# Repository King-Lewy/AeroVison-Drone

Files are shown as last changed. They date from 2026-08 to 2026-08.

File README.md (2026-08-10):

# AeroVison-Drone
A drone with a camera that connects to drone goggles to fly in first person view. 3d printed and custom frame. All parts were researched and chosen to not be too expensive, but still high quality. Sub $1000.

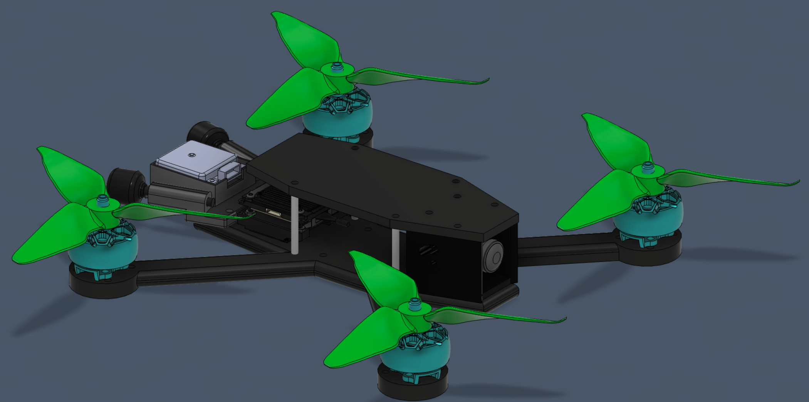
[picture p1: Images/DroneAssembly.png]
Assembly


Assembly with battery on top. 
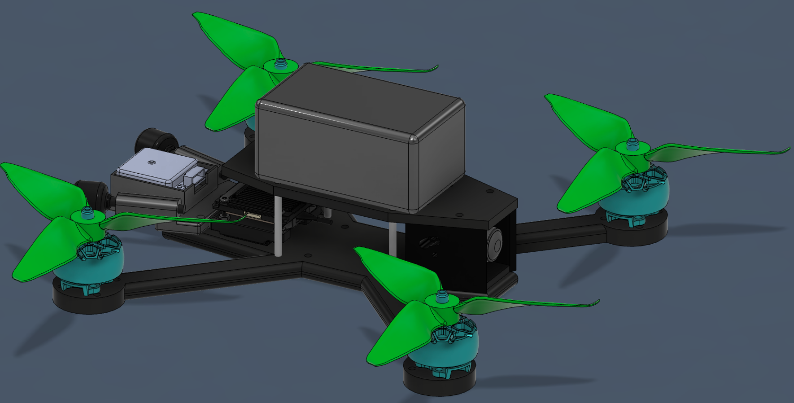
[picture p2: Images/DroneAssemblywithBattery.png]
Assembly with battery


### Why a Drone?
Every since my brother and I got a 3d printed a few years ago, we have wanted to design a drone, and 3d print the frame of it. But, we have never actually got around to doing it, either because we were busy, lazy, or didn't think that we could fund it. But, it was always still in our minds (at least my mind). Making a drone sounded really cool and fun, even though me personally, I didn't know anything about them, how they worked, or how expensive they would be, other than that I assumed that it would cost A LOT to make, which kind of discouraged me. 

## Starting the Project
Just like I mentioned before, I always wanted to make/have a drone, so the idea of making one was very exciting. The reason that I actually started though, was because my dad said that if I design a custom frame, and did all of the work doing all of the parts of designing the drone, he would fund the project for me. I instantly started to research every part of the drone. But, the first thing I did was start with a brainstorming session to get a few guidelines, and base things that needed to be achieved. These were the original guidelines:
 - Low-ish Cost but High Quality (sub $1000)
 - 3d Printed Frame
 - Live Feed Camera with Drone Goggles
 - 100ft Minimum flight height
 - Being Able to have the drone do a flip
 - Be able to survive crashes (I am a beginner, and I know I will crash a few times)

Most of these are basic things that all drones can do, but the one thing (other than a 3d printed frame) that isn't always found is the drone goggles with a live feed camera. This was one baseline that my dad really wanted out of this drone. Because he is funding the project, I can't argue (and I really wanted that too, so I wouldn't argue anyways). I knew that this would dramatically increase the price of this projects, but that's ok.

### Process of Designing a Drone
During research, I learned this process that is used when first starting to design a drone,
1. Choose Frame size
2. Choose Propeller Size (which kind of is chosen with the frame size)
3. Choose Motor Size
4. Choose Battery Voltage

The first thing that I did was find out what size I wanted the drone to be. I researched how big drones are that can fly outside, fast, and won't get blown away hard in the wind. I decided to choose a 5 inch drone (which means the propellers are 5 inch, not the actual frame). This completed the first two steps in the process, which means I needed to find a motor size, and then the battery voltage. 

When choosing the motor size, you have to account for the size of your frame and propellers, because the strength of the motor is in a direct relationship with those. The bigger your frame, the more weight you have to propel, and you need to make sure that the motors fit your propellers, and are strong enough to be used for a 5 inch frame. An additional requirement that I had was to make all of things crash resistant, so I needed a good motor that wouldn't break. I found one that could withstand high voltage, had a steel shaft so it wouldn't break in a crash, and is relatively cheap. 

Based on the size and voltage needed for my motors, that is how I chose my battery. I decided that I needed a 6s battery so there would be enough power to have good flight times, and propel the drone powerfully. Alos, the battery I chose weighed a little more, but that is because I needed it to be able to withstand crashes (per my requirements). 

### Parts Analysis
All of the "big" parts that I have chosen for this drone, I have done an analysis to find the best one that fits this project the best based on it's cost, performance, advantages, disadvantages etc. You can find these analyses in the "Part Analysis-Comparison" folder. These are the main parts the I did an analysis on:
 - Camera and VTX
 - Controllers and Receivers
 - 6s Batteries
 - Filament (When to use which filament)
 - FC+ESC Stack

These are some of the big components for the drone that I decided needed to be really well thought out. The only other big thing that I didn't do an analysis for, was the goggles, because they were the only relatively low cost goggles that still had good camera options.

# Build Instructions
- **Order All of the Necessary Parts**
Go through the BOM and buy all of the parts on the list. Tip: try to get the controller as soon as possible, so you can start practicing on an online simulator. For the 3d printed parts, I would first 3d print all of the parts in a prototype material (pla/petg) and make sure that all of the electronics fit. This also helps you know if there are any problems before printing with a more expensive filament, and it gives you build experience!

- **Assemble the Frame (prototype)**
For the frame, there are a few thing that you will need. The base plate, the standoffs, the top plate, and the mounting pieces for the camera and antenna (with the remote ID). You will assemble the frame first with the prototype material 3d print, to make sure that everything works well. You can also mount all of the electronics if you want, also to make sure the spacing is correct. It all should be fine, but case by case it might be different, and you don't want any problems to occur.

- **Wiring**
This is the hardest part of the whole project. You will need to follow the wiring diagram below to make sure that everything is wired correctly.

To explain the wiring diagram (speedybee V5), the four motors are soldered onto the esc (the bottom of the stack) as well as the cord that connects to the battery, and the capacitor (little cylinder like thing). The order of the motor wires doesn't matter, but for the red and black big wire, the red goes to the positive side, and the black on the negative. The capacitor is the same way. Then, the esc, and fc are connected with a wire provided in the stack kit, and the fc will be on the top. There are three main things that connect to the FC, the receiver, the VTX, and the remote ID/GPS module. The receiver is connected on the specific soldering pods as shown below, but in the patter of (-,gnd)(5V,4V5)(TX,R2)(RX,T2). The VTX is the other part that connects to the receiver, but there is no welding required for this one. On the side of the stack (the one shown in the diagram), there is a wire plug port for a 6 pin wire, which you plug in, then you plug in the other end into the VTX. For this specific design, you have to use a 4 pin to 6 pin wire, because the VTX only has a 4 pin option, and the stack only has a 6 pin, but thankfully, there are wires (in the BOM to account for this). The last thing that connects to the fc (other than the esc) is the remote ID/gps module. This is attached in a very specific manner. Both the remote id, and the stack have 6 pin ports for it to plug into, but there is a big problem, the pin sizes are different, so it won't be able to fit into the stack (because it is smaller). So, you receive a wire in the remote id kit that you will cut of the pin on one side, and keep the other side. You will plug the pin into the slot on the remote id, but for the stack you have to solder it onto the specific ports as shown on the wiring diagram. The only other way to do this (without soldering), is to change the pin size with parts you have, but that is much harder (in my opinion), and I will personally not be doing that. Then, the camera and antennas connect to the vtx in their specific ports as shown in the image.

In the diagram, I want to point out some of the confusing features, because this is the only way that made sense for me to make it. The part that the motors connect to is the esc, and the esc connects to the fc from the rainbow wire. But, in the image it shows the bottom of the fc, because that is where the port for the pin is, as well as the soldering pods for the remote id, and the slot for the 6 pin wire that connects to the vtx. Above the upside down fc, is the top of the fc. This is where you solder on the wires that connect to the receiver. For the remote ID module, one confusing part is that where it connects in the image is actually just a zoomed in version of the bottom of the fc where it connects. This is actually located next to where the esc connects, and I tried to point this out with the pink circles, but it is kind of hard to tell. Also, the remote id module is upside down in the picture, because that is where the ports are, but it needs to be right side up for broadcasting. 

While wiring, it is very important that you first screw everything into place (motors, vtx, camera, stack, remote id) and mark on the wires where you need to cut them to be the proper length for your specific drone. You want to cut it a little longer than you expect, because a little extra wire isn't bad, and if you mess up, you can then cut the wire again to fix it (to the proper size). After you mark where they need to be cut, you actually need to take off the electronics, so you can actually wire them together. This starts with the motors that you will need to weld onto the esc (review the diagram), then you need to weld on the receiver (also the diagram), and then you put the stack on top of each other, and plug those together. Then, you screw back in all of the electronics, making sure that you have the right motors in the right spots (because you cut the wires to that specific length), and your stack in the right direction. After you have screwed in the VTX, antennas, and camera, you thread the camera wire through the middle of the stack, and plug that into the vtx. Then you plug in the two antennas to the VTX, and finally plug the VTX into the FC. When you plug in the battery, make sure to use the smoke stopper first, so if you messed up on your welds, it won't fry your system. Very important. 

For this part, you will screw down and measure based off of the Nylon-cf frame (the real thing, not prototype) and screw down all of the electronics/motors there. You only need to use the base of the frame, at this point don't worry about the standoffs or the top piece.

- **Assemble the Frame Part 2 (The real deal)**
Now that you have all of the wiring done, and the electronics cut to size (wires), you need to add the standoffs, and the top plate, and to put on the electronics on the real deal. First, you will screw on the electronics (that are already wired/soldered) in their correct places, and make sure that everything looks right. For the remote id module, there are no screw holes, and it goes in the box connected to the antenna holder. You will put a piece of double sided tape on the bottom of the box, and you need to tape down the edges of the remote id after you put it in. You will screw M3 screws from the top plate down into the standoff, and from the main frame body up into the standoffs. The standoffs are threaded, so you don't have to worry about bolts. 

- **Tape the wires down**
Now that you have all of the wires and electronics in the right place, you need to tape them down. This is to protect them, and to keep the from wiggling. The main place you will tape is the X arms, where the wires connecting to the motors are, so those are protected during a crash. you might think that it is weird that the receiver is not screwed in anywhere, and if you can't find a place to tuck that in, you can tape that down as well. All of the other wires will probably be fine to not tape down, but it is a case by case thing.

- **The Battery**
There is more than just adding the battery when you are talking about this drone. You will first (as I mentioned above) use the smoke stopper when you plug in, to make sure that it is fine. If you hear two seperate beeps, then you are all set, and you can remove the smoke stopper, and re-plug it in. If you don't, then there is a problem with the soldering, and you will have to review it. Then, you will need to attach your battery pad onto the top plate. It is pretty big, so you will first have to trim it to the size of your top plate, then stick it on. When you go to fly, you will have to put the battery onto that top plate, then you have to strap the battery in, with the battery straps. You need to order two of these, so that you can strap it down on both sides of the battery. You can either strap it around only the top plate, or both the top and bottom plate. Your choice.

- **Software configuration**
Now go into Betaflight, and configure it how you want to fly it. You need to calibrate the sensors, test the motor direction to make sure they are the right way. This is all personal preference, so you can configure it how you want. I have not done this yet (because I haven't built it yet), and I will record what I did after I do it myself.

- **Final Add On**
Add on the propellers and double check that each screw is put on correctly. If you want you can add lock tight to the screws so they don't unscrew. That is totally optional though. Make sure to add both of the battery straps each time you fly. 

- **Registration/Legality**
This is the part that you register your drone, and become legal to fly. You need to understand where you can fly (uncontrolled airspace), and become registered. At least in the united states (I don't know about other places) you need to go through faa drone zone, make an account, and start to register your drone. There are two parts in being able to fly your drone, one is the actual registration of your drone (which is kind of registering you as a pilot, not just the drone) and taking the TRUST test. I would first take the trust test, because this certifies that you know the rules and expectations of flying, and then actually register. The registration will be $5, and is to tell people that you are a certified pilot. You need to insert your drone into their catalogues, including its ID (on the remote ID package), size, and who made it. Then, you have to pay the fee, and become certified. Once it is accepted, you need to put your certification number onto your drone, on the outside, so it is visible while flying. You will learn about this during the TRUST test.

At this point, you should be legal to fly, and you are now ready to fly FPV!

# Wiring Diagram
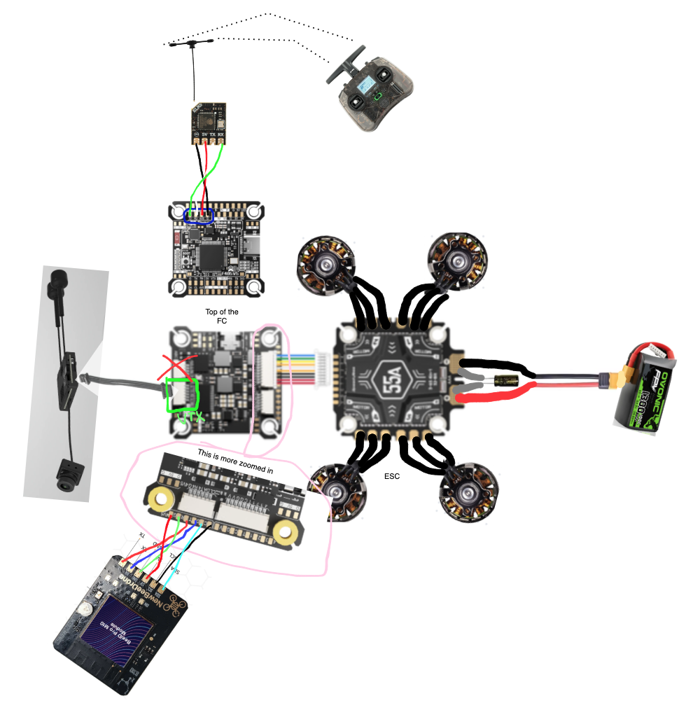
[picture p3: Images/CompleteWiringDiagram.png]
Wiring Diagram


### Original Planning Whiteboard
This isn't really necessary, but here is an image of the original planning whiteboard that I used to first start this project. 

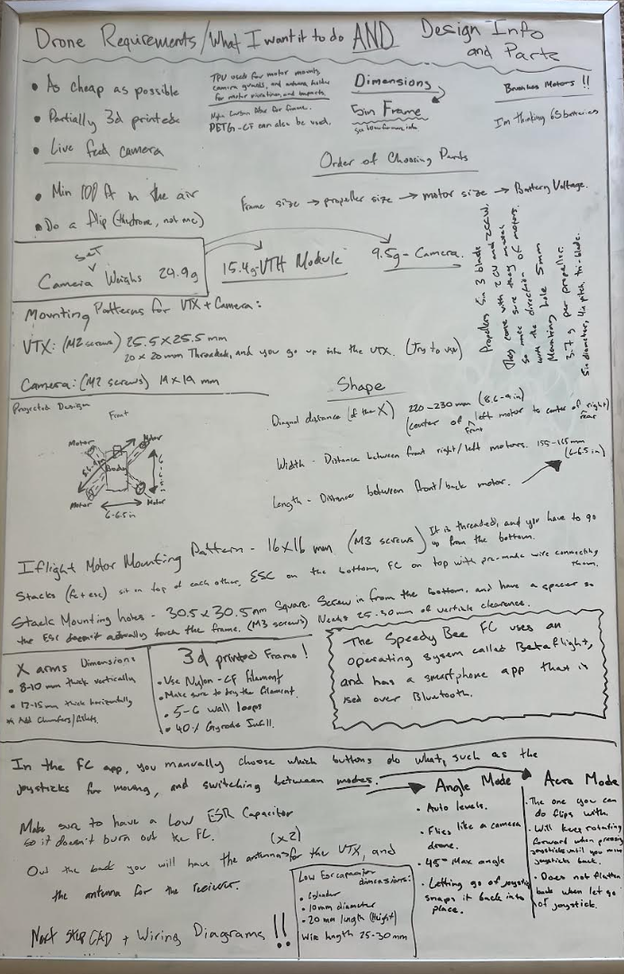
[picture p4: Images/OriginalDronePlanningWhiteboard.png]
Planning Whiteboard


### Camera Mount/Antenna Holder/Main Frame
The parts that I specifically designed were the camera mount, antenna holder, and the mainframe. The assembly is made up of these parts, and a compilation of other parts that I found online for free, such as the motors, camera, vtx, and the actual antennas. I did put together all of the parts of the drone assembly, but the parts that I actually designed were these ones. 

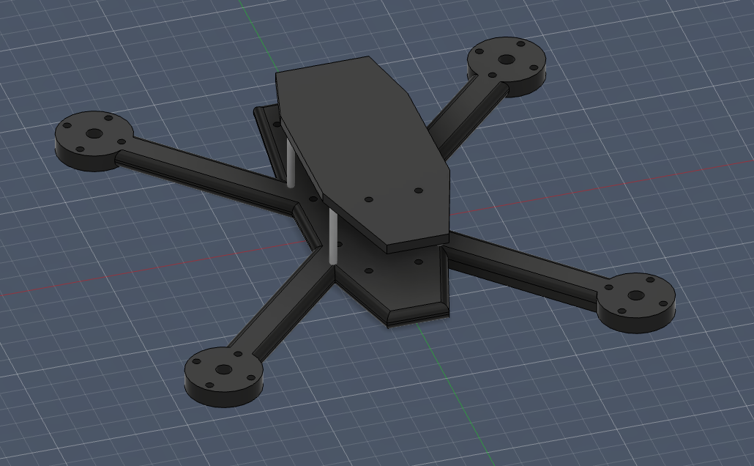
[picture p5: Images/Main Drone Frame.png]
Drone Frame

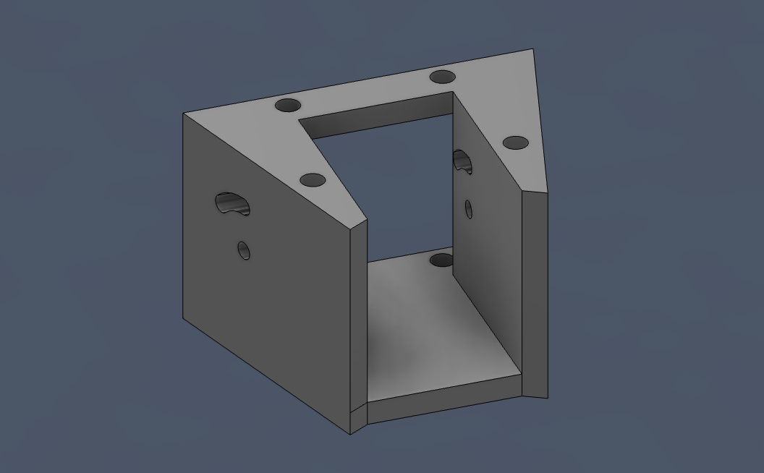
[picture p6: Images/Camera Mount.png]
Camera Mount

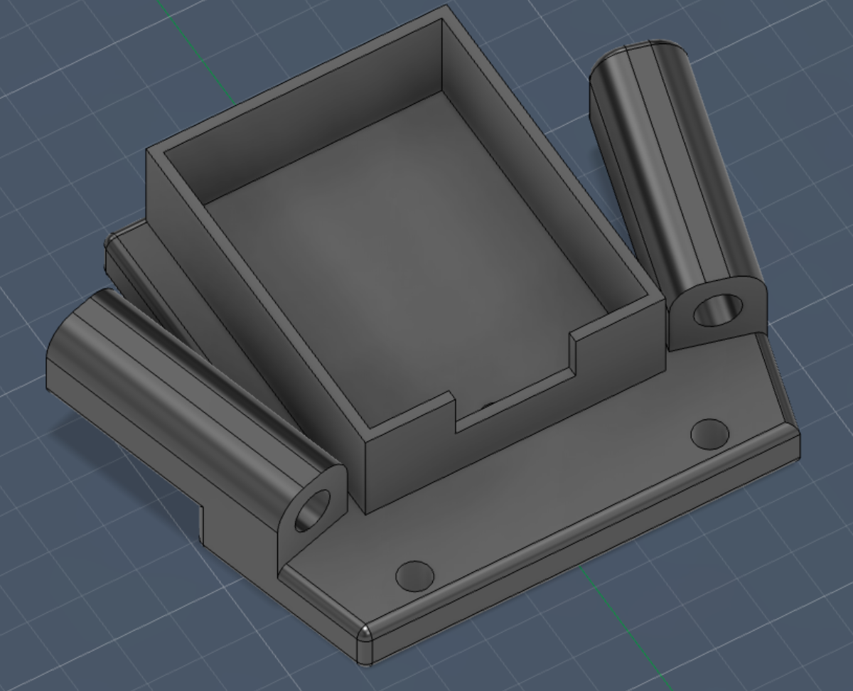
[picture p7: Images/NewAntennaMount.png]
Antenna Holder


## Example of 3d Printed Frame
So, I am still in the design, and buying parts phase of this project, but I 3d printed an example frame to show myself about the size of the drone, and to make sure the screw holes were right. For this edition, I 3d printed it out of PETG translucent, and low infill and 2 wall loops, just because this is a prototype, and not meant to actually fly. It still holds the same concept of the size and shape of drone, and is the same design that I will print later, just not as much filament. 

I printed the standoffs, even though in the actual thing they will be aluminum, but I attached the top and bottom plate, as well as the camera mount, and the antenna mount, which I printed out of tpu. I screwed them all together, and this is what I got.  

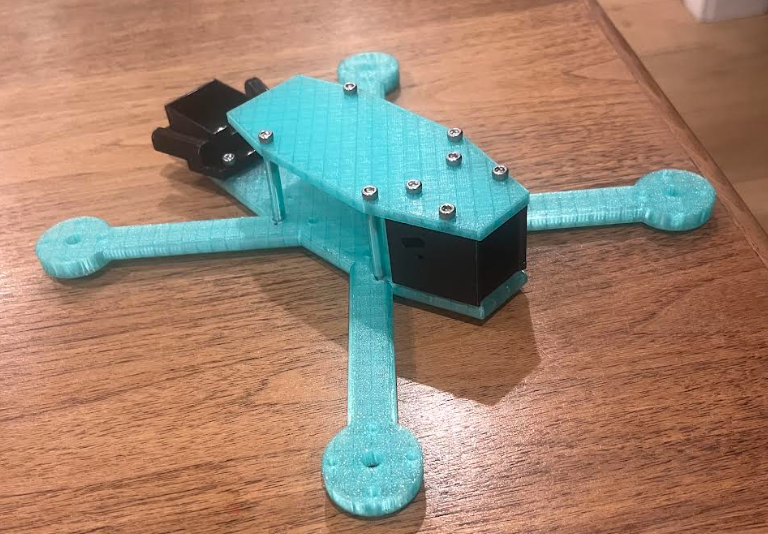
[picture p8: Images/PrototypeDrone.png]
3d print


# BOM 
| Item (General Name) | Actual Name | Unit Price | Quantity | Total Price | URL |
|---|---|---|---|---|---|
| Drone Goggles | Walksnail Avatar HD Goggles L Only | $199.99 | 1 | $199.99 | https://www.caddxfpv.com/products/walksnail-avatar-hd-goggles-l-only |
| Camera/Antena/VTX | Walksnail Avatar HD Pro Kit (Dual) | $169.00 | 1 | $169.00 | https://www.caddxfpv.com/products/walksnail-avatar-hd-pro-kit-dual-antenna |
| 4 Propellers | HQ Prop Ethix S5 Light Grey (2CW+2CCW)-Poly Carbonate | $3.49 | 3 | $10.47 | https://www.readymaderc.com/products/details/hq-prop-ethix-s5-cinematic-propeller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 |
| 4 Motors | XING2 2207 1855KV 3-6S / 2755KV 3-5S Brushless FPV Motor for IFlight with 5mm Titanium Alloy Shaft for 5.1inch Propeller RC FPV Drones (4pcs 2207 1855kv) | $77.30 | 1 | $77.30 | https://www.amazon.com/Brushless-IFlight-Titanium-5-1inch-Propeller/dp/B0DG8QN6KY?th=1 |
| FC+ESC Stack | SpeedyBee F405 V5 OX32 55A 30x30 Model Aircraft FC & ESC Stack | $126.05 | 1 | $126.05 | https://www.readymaderc.com/products/details/86580-speedybee-f405-v5-ox32-55a-30x30-model-aircraft-fc-esc-stack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 |
| .5 Kg Nylon-CF | Fiberon™ PA6-CF20 | $39.99 | 0 (already own) | 0 | https://shop.polymaker.com/products/fiberon-pa6-cf20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 |
| .75 Kg of TPU | PolyFlex™ TPU95 | $29.99 | 0 (already own) | 0 | https://shop.polymaker.com/products/polyflex-tpu95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 |
| Controller | Pocket Radio Controller (M2) | $71.50 | 1 | $71.50 | https://radiomasterrc.com/products/pocket-radio-controller-m2 |
| Reciever | RP1 V2 ExpressLRS 2.4ghz Nano Receiver | $18.99 | 1 | $18.99 | https://radiomasterrc.com/products/rp1-expresslrs-2-4ghz-nano-receiver |
| Battery x4 | Ovonic 6S 1300mAh 100C 22.2V LiPo Battery with XT60 Plug for 5-6 Inch FPV Freestyle Drone | $59.99 | 1 | $59.99 | https://us.ovonicshop.com/products/ovonic-100c-1300mah-6s1p-22-2v-xt60-4pcs-lipo-battery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 |
| Battery Strap | Kevlar Fly High FPV Lipo Strap for 5"" quads 250mm | $5.00 | 2 | $10.00 | https://flyhighfpv.com/products/kevlar-lipo-straps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 |
| Batteries for Controller | Molicel M35A 18650 3500mAh 10A Battery | $6.99 | 2 | $13.98 | https://18650battery.com/products/molicel-m35a-18650-3500mah-10a-battery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 |
| Battery Charger | 608 AC Lipo Battery Charger,AC 50W/DC 200W Dual Mode RC Discharger/Charger | $64.99 | 1 | $64.99 | https://isdtshop.com/products/isdt-608ac |
| Standoffs | M3 Knurled Aluminum Standoff - 5Pcs. | $3.99 | 1 | $3.99 | https://pyrodrone.com/products/textured-aluminum-stand-off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 |
| Solder | Rosin Core Solder 60/40 (1/2 oz) | $1.40 | 1 | $1.40 | https://kingcobrahobby.com/products/miniatronics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 |
| Soldering Flux | No Clean Solder Paste Flux, 10g/50g Semi-Solid Soldering Paste for Electronics, Strong Welding Power for Circuit Board Repair and Electrical Soldering，10g | $5.99 | 1 | $5.99 | https://www.amazon.com/BEEYUIHF-Dropper-Soldering-Electrical-Squeeze/dp/B0FR3SKG1W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 |
| M2 Screws | 1110 Pcs M2 Screws Kit, M2 Machine Screws and Nuts and Washers Set, Assorted Stainless Steel Button Head Socket Cap Screws Nuts and Bolts Assortment Kit, Metric Screw Assortment, Fully Threaded | $7.99 | 1 | $7.99 | https://www.amazon.com/Machine-Assorted-Stainless-Assortment-Threaded/dp/B0DFWXRM21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 |
| M3 Screw | 22 (9mm) This kit has everything you will need. | $9.99 | 0 (already own) | $0.00 | https://www.amazon.com/Fgruh-750PCS-Assortment-Washers-Assorted/dp/B0FGV5FCBN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 |
| Battery Pad | 2PCS 12×8"" Car Battery Mat Cuttable Battery Protector Mat for Protecting Batteries State Anti Shock & Anti Vibration Batteries Box Pad Car Accessories for Most Boats & Trucks | $0.05 | 1 | $0.05 | https://www.getfpv.com/lumenier-qav-rxl-2-battery-pad.html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 |
| 4 to 6 pin wire | Walksnail VTX Connecting FC Cable | $2.99 | 1 | $2.99 | https://www.caddxfpv.com/products/walksnail-vtx-connecting-fc-cable |
| Smoke Stopper | JHEMCU Smoke Stopper 1-6S XT60 / XT30 Resettable In-Line Fuse Short Circuit Protection | $4.99 | 1 | $4.99 | https://speedyfpv.com/products/jhemcu-rc-smoke-stopper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 |
| Remote ID/GPS | NewBeeDrone BeeID Pro M10 GPS Module with RemoteID & IST8310 Compass | 59.99 | 1 | 59.99 | http://newbeedrone.com/products/newbeedrone-beeid-pro-m10n-gps-module-with-remoteid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 |

## Understanding CAD Files
I have a method the I used that I think is organized, but I am putting a guide, just so it is easy to know where to find any files. All of the CAD files will be found in the CAD folder, and there are a few images of the CAD in the images folder. This is how it is organized

Folders:
- Assembly (All parts included, finished design, .step and .f3d)
- Main Frame (Only the base frame and the top plate with standoffs connecting them, .step and .f3d)
- .STL (Camera/Antenna mounts, Frame)(The parts you will 3d print)

Individual Files (.step)
- Antenna Holder 
- Camera Mount 
- Motors
- Propellers
- Camera + VTX + Antenna

I don't have a stack model, but the dimension are accurate to the real thing. Don't worry. Also, I have .step files for all of the little things like mounts, and I added .f3d files for the bigger things like the assembly, and the mainframe. I hope this helps. 

### Overview and License
This project has taught me a lot about electronics, and how wiring works. I am improving on my CAD (which isn't very good, yet), and it has been a good opportunity for me to start learning new CAD skills, and skills pertaining to drones in general. I used the MIT Licence.

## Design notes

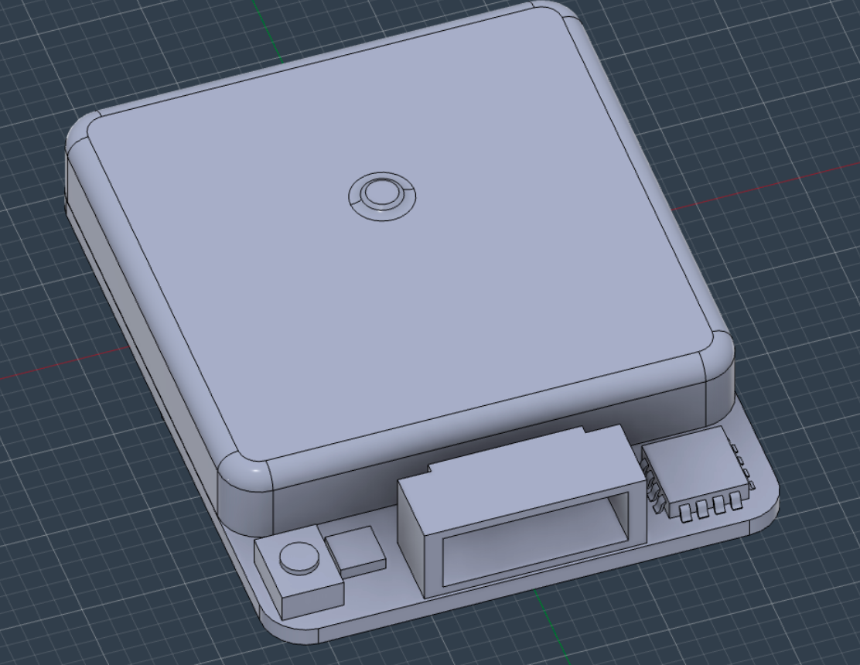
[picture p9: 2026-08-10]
Images/GPS+RemoteID.png

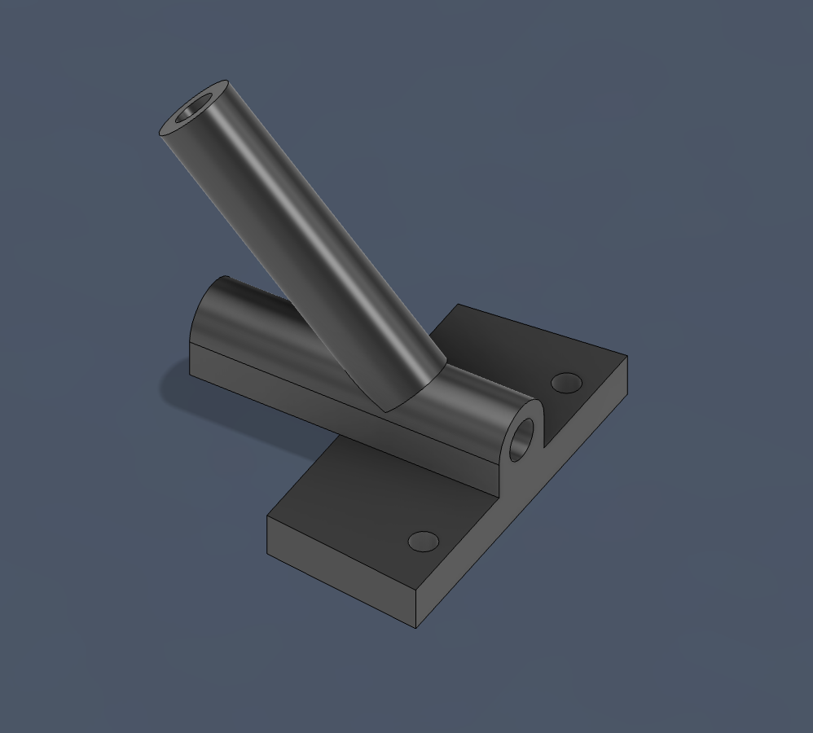
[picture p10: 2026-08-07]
Images/Antenna Holder.png

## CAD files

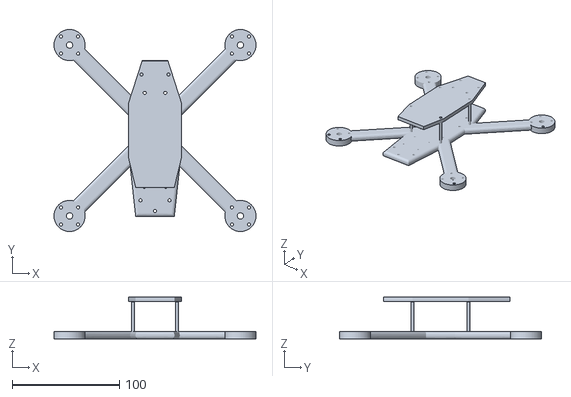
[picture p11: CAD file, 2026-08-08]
CAD/.STL/Drone Frame.stl
188.1 x 188.1 x 39.0

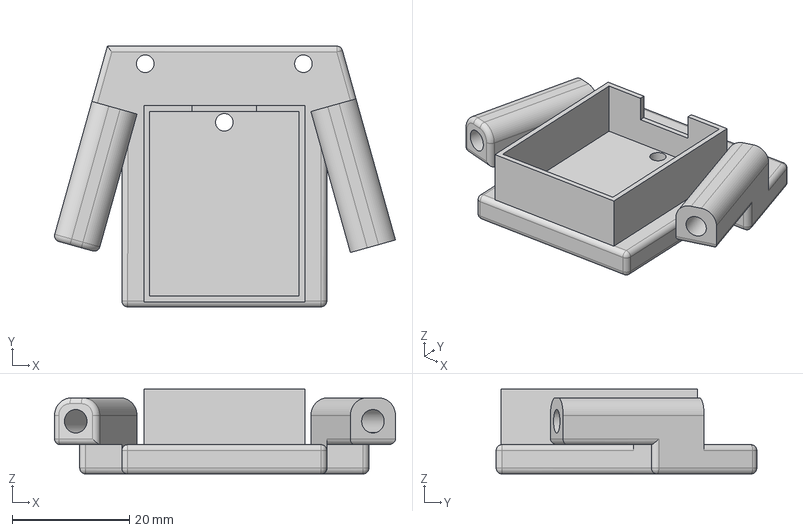
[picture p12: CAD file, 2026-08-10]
CAD/Antenna Mount New.step
58.2 x 44.5 x 14.5 mm

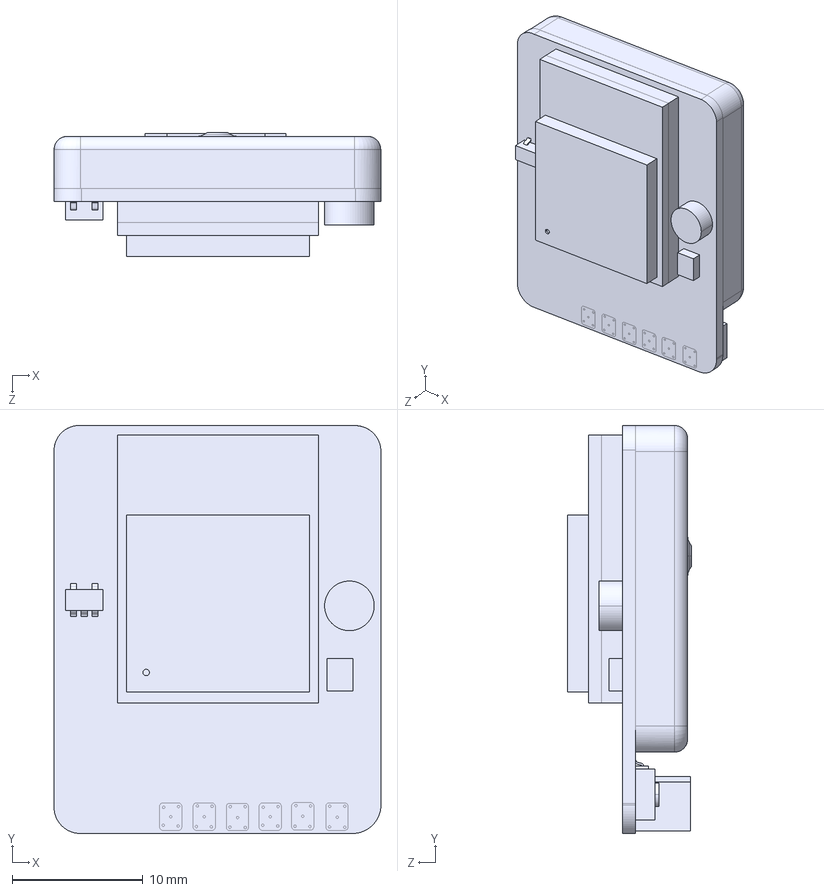
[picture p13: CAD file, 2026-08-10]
CAD/Remote ID .STEP
25.0 x 31.2 x 9.50 mm

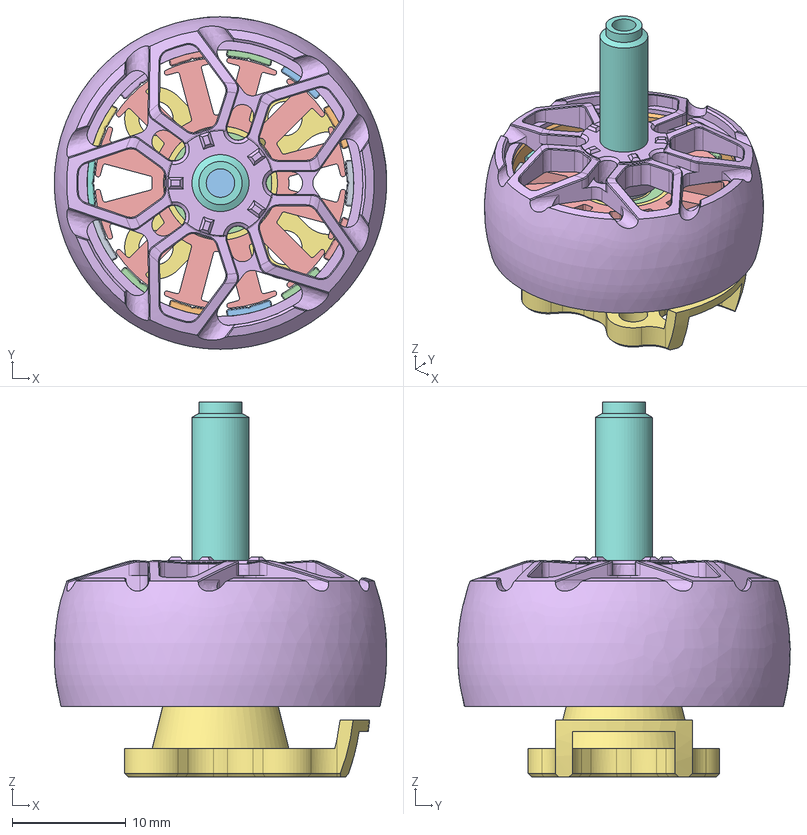
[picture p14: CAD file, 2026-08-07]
CAD/Drone Motor iflight.step
29.2 x 29.2 x 32.9 mm
magnets
flox_ring
washer
shaft
ring
spacer
screw
bearing_bot
bearing_top
stator
bell
feet

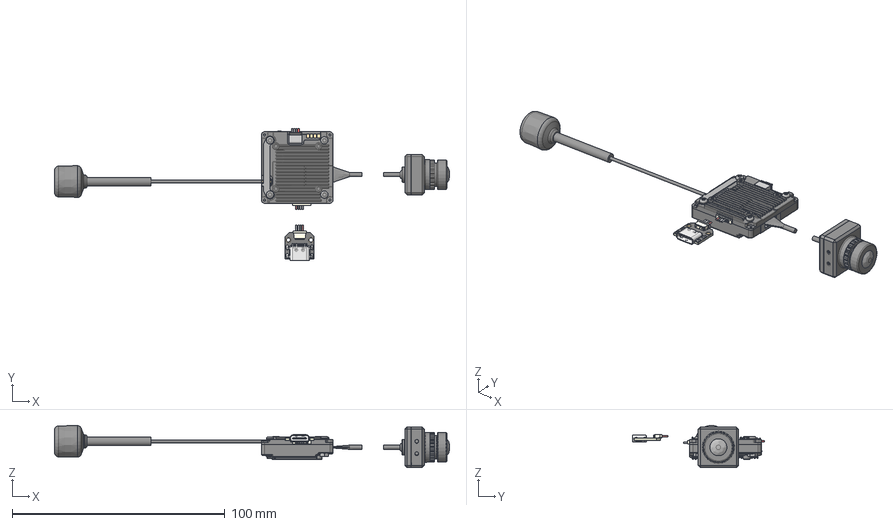
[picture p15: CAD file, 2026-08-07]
CAD/Camera + VTX.step
185.5 x 62.1 x 19.7 mm
Casing Top (1)
Casing Bottom (1)
Board Components
FC Connector
BM-1.0 6pin Female
M2x8
M2 Nuts
UFL Connector
Walksnail Avatar HD Camera
BM-1.0 4pin
USB-C
SH-1.0 4pin
SH-1.0 6pin Male 100mm Cable

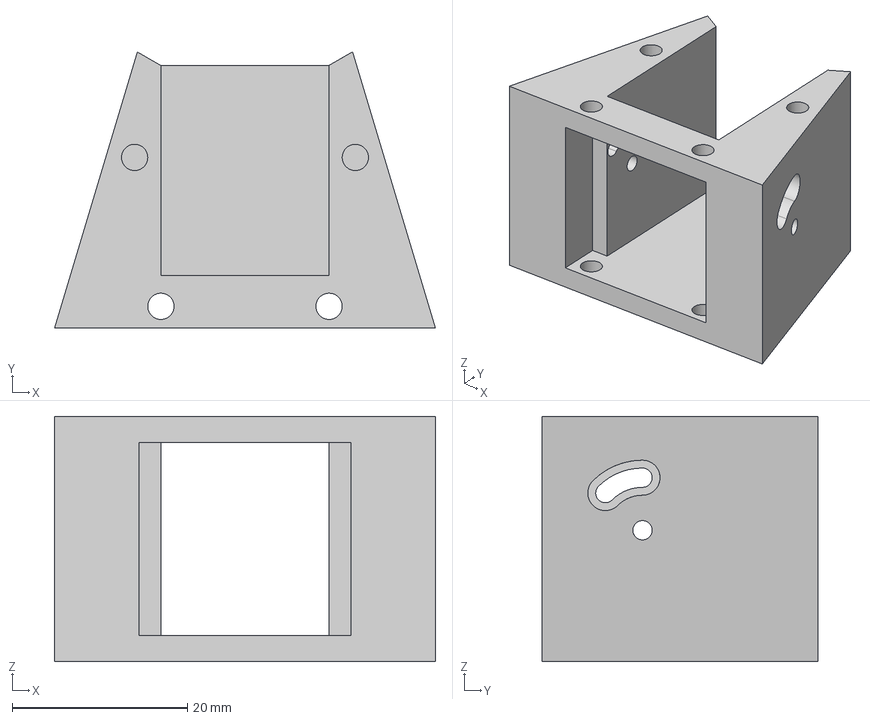
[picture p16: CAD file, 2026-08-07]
CAD/Camera Mount-Gaurd.step
43.5 x 31.6 x 28.0 mm

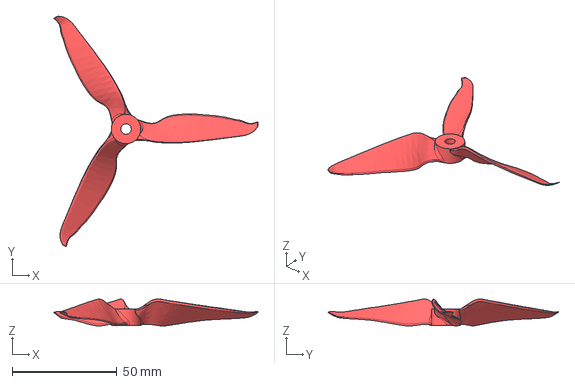
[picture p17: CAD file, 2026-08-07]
CAD/Propeller CW Puller.step
97.3 x 109.9 x 12.9 mm

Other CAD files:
CAD/Frame/Drone Frame.step
CAD/.STL/Antenna Mount New.stl
CAD/.STL/Camera Mount-Gaurd.stl
CAD/Frame/Drone Frame.f3d
